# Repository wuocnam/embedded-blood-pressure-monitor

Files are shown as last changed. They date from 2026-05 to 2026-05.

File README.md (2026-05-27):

z7873015730073_17597a3d94fae7621c3b929b31e877bd# Embedded Blood Pressure Monitor

A real-time, non-invasive blood pressure monitoring system utilizing an embedded microcontroller and a custom-designed analog front-end for high-precision sensor data acquisition.

## 📸 Product Showcase
z7873014103155_68d4da9852d3bea1b45f12b7498baded
z7873015730836_ad06e7b14a9b0673478aa2cc813ee6c5

## 🛠️ Hardware & System Design
- **Microcontroller:** Arduino Nano (ATmega328P) with 16x2 LCD UI.
- **Pressure Sensor:** MPS20N0040D (0-40kPa).
- **Custom Analog Front-End (Signal Conditioning):** - High-precision instrumentation amplification using **AD620**.
  - Multi-stage active filtering using **LM741** Op-Amps.
- **Power Management:** Dual power supply design using **LM7805** (+5V) and **ICL7660S** (-5V for Op-Amp symmetrical rails).
- **Power Drivers:** Transistor-based driving circuits (**TIP41C**, **2N2222**) with flyback protection for actuators.
- **Actuators:** Mini air pump, solenoid release valve, and speaker.

## 📂 Repository Structure
- `/hardware`: Contains schematic snippets demonstrating the custom signal conditioning and power distribution networks.
- `/firmware`: Embedded C/C++ source code for sensor calibration, UI control, and actuator management.

## 🚀 Key Signal Routing
- **MPS Sensor Output** -> AD620 Instrumentation Amp -> LM741 Active Filters -> **Arduino ADC0**
- **Motor/Valve Control** -> Arduino D2, D3 -> TIP41C Driver Network

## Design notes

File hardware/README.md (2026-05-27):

Contains Altium schematic and PCB layout files.

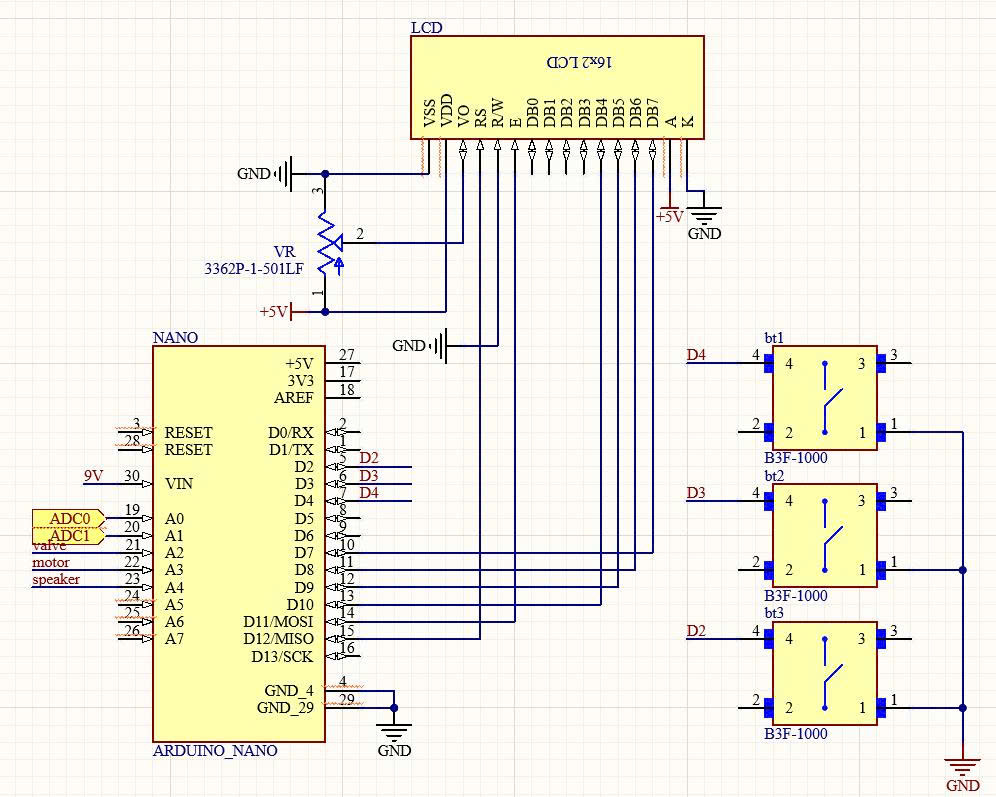
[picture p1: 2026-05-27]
hardware/z7873002787466_9863b803301838057b1b3febb424fb58.jpg

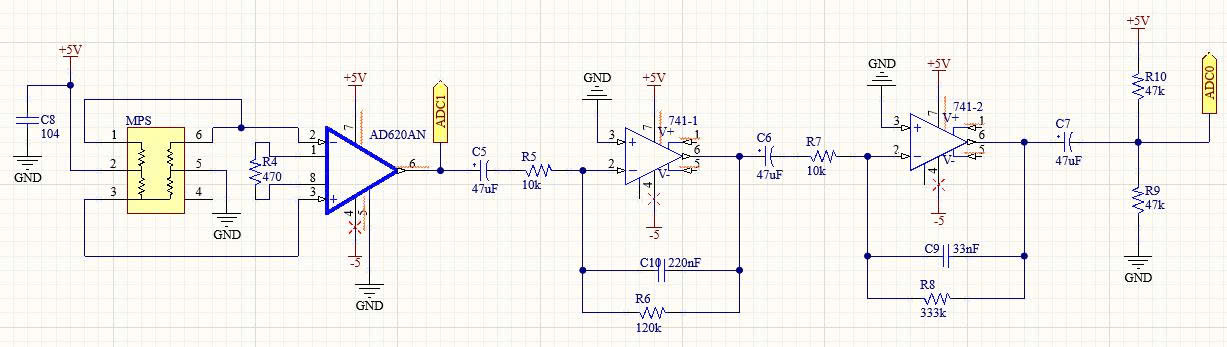
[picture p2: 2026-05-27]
hardware/z7873003652954_3d97f664d1a321c22de6d83c76b436e1.jpg

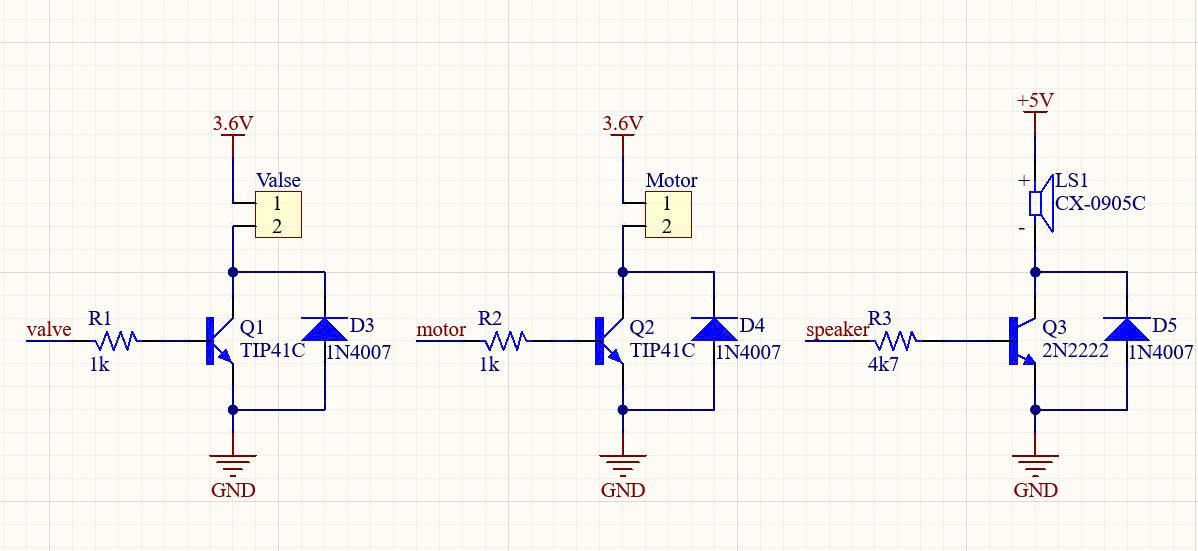
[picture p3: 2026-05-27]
hardware/z7873000200435_f1b9de5734167418a74198fc22bee216.jpg

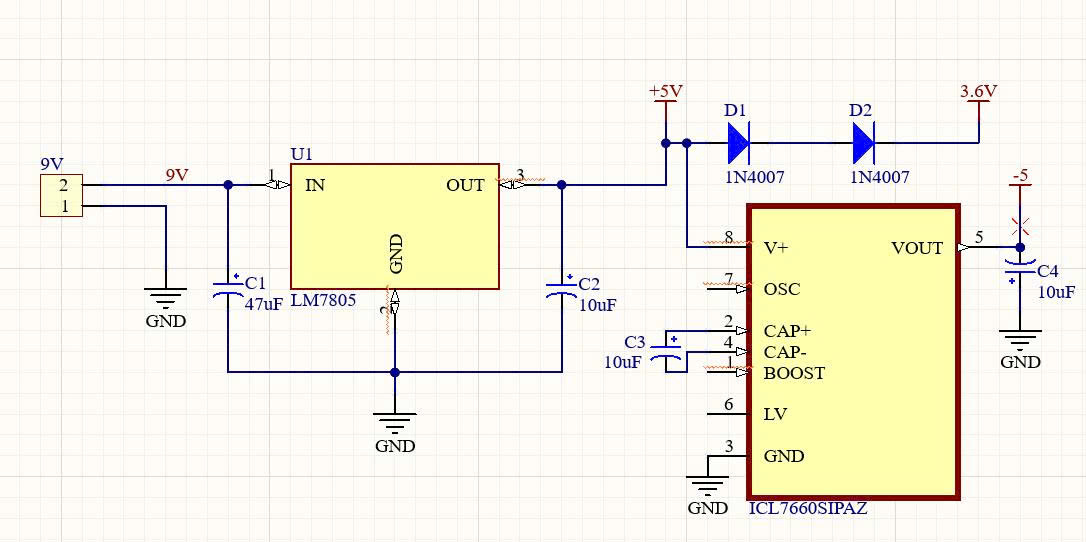
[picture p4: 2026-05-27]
hardware/z7873000130149_b3070aff2e2c831d72ec8909d467a5be.jpg

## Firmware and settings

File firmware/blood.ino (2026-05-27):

#include <avr/interrupt.h>
#include <LiquidCrystal.h>

#define on HIGH
#define off LOW

#define startState 0
#define inflate1State 1
#define inflate2State 2
#define deflateState 3
#define displayState 4
#define resetState 5

#define Sys_Measure 6
#define Rate_Measure 7
#define dias_Cal 8

#define valve A2
#define motor A3
#define speaker A4

#define bt_start 4
#define bt_stop 3
#define bt_resume 2

#define ADC0 A0
#define ADC1 A1

LiquidCrystal lcd(12,11,10,9,8,7);

unsigned char currentState;
unsigned char meas_state;

volatile unsigned int timepress0 = 0;
volatile unsigned int timepress1 = 0;
volatile unsigned int timepress2 = 0;

volatile unsigned int timing = 0;
volatile unsigned int timerate = 0;
volatile unsigned int timecount = 0;
volatile unsigned int timedeflate = 0;

volatile unsigned int speaker_timer = 0;

float Vref = 5.0;
float DC_gain = 105;

int data;
float adc_data;
float former;

float filtered_adc0 = 0;
float filtered_adc1 = 0;

float pressure = 0;
float maxpressure = 80;

float systolic = 0;
float diastolic = 0;
float pulse_per_min = 0;

float total_pulse_period = 0;

unsigned char count_average = 0;
unsigned char countpulse = 0;
unsigned char sys_count = 0;
unsigned char stop_count = 0;

float TH_sys = 4.9;
float TH_rate = 2.5;

static inline unsigned int read_u16(volatile unsigned int *v)
{
  unsigned int tmp;

  noInterrupts();
  tmp = *v;
  interrupts();

  return tmp;
}

static inline void write_u16(volatile unsigned int *v,
                             unsigned int val)
{
  noInterrupts();
  *v = val;
  interrupts();
}

void start_state(void);
void inflate1_state(void);
void inflate2_state(void);
void deflatestate(void);
void display_state(void);
void reset_state(void);

void pressuremeasure(void);
void sysmeasure(void);
void ratemeasure(void);
void diascal(void);

void read_adc(int Channel);

void setup()
{
  Serial.begin(9600);

  ADCSRA = (ADCSRA & 0xF8) | 0x07;

  pinMode(bt_start, INPUT_PULLUP);
  pinMode(bt_stop, INPUT_PULLUP);
  pinMode(bt_resume, INPUT_PULLUP);

  pinMode(motor, OUTPUT);
  pinMode(valve, OUTPUT);
  pinMode(speaker, OUTPUT);

  digitalWrite(motor, off);
  digitalWrite(valve, off);
  digitalWrite(speaker, LOW);

  lcd.begin(16,2);

  lcd.setCursor(0,0);
  lcd.print("White: Start");

  lcd.setCursor(0,1);
  lcd.print("Grey: Stop");

  cli();

  TCCR1A = 0;
  TCCR1B = 0;
  TIMSK1 = 0;

  TCCR1B |= (1 << WGM12);
  TCCR1B |= (1 << CS11) | (1 << CS10);

  OCR1A = 249;

  TIMSK1 |= (1 << OCIE1A);

  sei();

  write_u16(&timing,40);

  currentState = startState;
  meas_state = Sys_Measure;
}

void loop()
{
  switch(currentState)
  {
    case startState:
      start_state();
      break;

    case inflate1State:
      inflate1_state();
      break;

    case inflate2State:
      inflate2_state();
      break;

    case deflateState:
      deflatestate();
      break;

    case displayState:
      display_state();
      break;

    case resetState:
      reset_state();
      break;
  }
}

ISR(TIMER1_COMPA_vect)
{
  if(digitalRead(bt_start) == LOW)
    timepress0++;

  if(digitalRead(bt_stop) == LOW)
    timepress1++;

  if(digitalRead(bt_resume) == LOW)
    timepress2++;

  timecount++;
  timedeflate++;

  if(speaker_timer > 0)
  {
    digitalWrite(speaker,HIGH);
    speaker_timer--;
  }
  else
  {
    digitalWrite(speaker,LOW);
  }

  if(timing > 0)
    timing--;

  if(timerate < 65535)
    timerate++;
}

void start_state(void)
{
  if((digitalRead(bt_start) == LOW) &&
     (read_u16(&timepress0) > 30))
  {
    write_u16(&speaker_timer,100);

    pressure = 0;

    systolic = 0;
    diastolic = 0;
    pulse_per_min = 0;

    total_pulse_period = 0;

    count_average = 0;
    countpulse = 0;
    sys_count = 0;
    stop_count = 0;

    filtered_adc0 = 0;
    filtered_adc1 = 0;

    former = TH_sys - 0.01;

    meas_state = Sys_Measure;

    lcd.clear();

    lcd.setCursor(0,0);
    lcd.print("Inflating");

    digitalWrite(valve,off);

    digitalWrite(motor,on);

    currentState = inflate1State;

    write_u16(&timepress0,0);
    write_u16(&timecount,0);
  }
}

void inflate1_state(void)
{
  if(read_u16(&timecount) >= 1000)
  {
    lcd.setCursor(0,1);
    lcd.print("P=");
    lcd.print(pressure);
    lcd.print("     ");

    write_u16(&timecount,0);
  }

  if((digitalRead(bt_stop) == LOW) &&
     (read_u16(&timepress1) > 30))
  {
    digitalWrite(motor,off);
    digitalWrite(valve,off);

    currentState = resetState;

    write_u16(&timepress1,0);
  }
  else
  {
    currentState = inflate2State;
  }
}

void inflate2_state(void)
{
  read_adc(1);

  pressure = (adc_data / DC_gain) * 2000;

  Serial.print("Pressure: ");
  Serial.println(pressure);

  if(pressure >= maxpressure)
    stop_count++;
  else
    stop_count = 0;

  if(stop_count >= 5)
  {
    lcd.clear();

    lcd.setCursor(0,0);
    lcd.print("Deflating");

    digitalWrite(motor,off);

    delay(100);

    currentState = deflateState;

    write_u16(&timedeflate,0);
  }
  else
  {
    currentState = inflate1State;
  }
}

void deflatestate(void)
{
  unsigned int timedeflate_local =
    read_u16(&timedeflate);

  if(timedeflate_local >= 100)
  {
    write_u16(&timedeflate,0);
    timedeflate_local = 0;
  }

  if(timedeflate_local < 50)
  {
    digitalWrite(valve,on);
  }
  else
  {
    digitalWrite(valve,off);
  }

  if((digitalRead(bt_stop) == LOW) &&
     (read_u16(&timepress1) > 30))
  {
    digitalWrite(motor,off);
    digitalWrite(valve,off);

    currentState = resetState;

    write_u16(&timepress1,0);
  }

  pressuremeasure();
}

void pressuremeasure(void)
{
  if(read_u16(&timing) != 0)
    return;

  switch(meas_state)
  {
    case Sys_Measure:
      sysmeasure();
      break;

    case Rate_Measure:
      ratemeasure();
      break;

    case dias_Cal:
      diascal();
      break;
  }
}

void sysmeasure(void)
{
  read_adc(0);

  read_adc(1);

  pressure = (adc_data / DC_gain) * 2000;

  if(former <= TH_sys &&
     adc_data > TH_sys)
  {
    sys_count++;
  }

  former = adc_data;

  if(sys_count >= 2)
  {
    systolic = pressure;

    meas_state = Rate_Measure;

    former = TH_rate - 0.01;

    count_average = 0;
    countpulse = 0;

    total_pulse_period = 0;

    write_u16(&timerate,0);
  }

  if(read_u16(&timecount) >= 1000)
  {
    lcd.clear();

    lcd.setCursor(0,0);
    lcd.print("Measuring");

    lcd.setCursor(0,1);
    lcd.print(pressure);

    write_u16(&timecount,0);
  }
}

void ratemeasure(void)
{
  read_adc(0);

  if(read_u16(&timerate) > 5000)
  {
    pulse_per_min = 0;

    meas_state = dias_Cal;

    return;
  }

  if(former < TH_rate &&
     adc_data > TH_rate &&
     read_u16(&timerate) > 450)
  {
    if(countpulse == 0)
    {
      write_u16(&timerate,0);
      countpulse = 1;
    }
    else
    {
      total_pulse_period +=
        read_u16(&timerate);

      write_u16(&timerate,0);

      count_average++;
    }

    write_u16(&speaker_timer,30);
  }

  former = adc_data;

  if(count_average >= 5)
  {
    pulse_per_min =
      (5.0 * 60000.0) /
      total_pulse_period;

    lcd.clear();

    lcd.setCursor(0,0);
    lcd.print("Pulse");

    lcd.setCursor(0,1);
    lcd.print(pulse_per_min);

    meas_state = dias_Cal;
  }
}

void diascal(void)
{
  read_adc(1);

  pressure = (adc_data / DC_gain) * 2000;

  diastolic = pressure;

  digitalWrite(valve,off);

  write_u16(&speaker_timer,500);

  currentState = displayState;

  write_u16(&timecount,0);
}

void display_state(void)
{
  if(read_u16(&timecount) >= 1000)
  {
    lcd.clear();

    lcd.setCursor(0,0);
    lcd.print("S:");
    lcd.print(systolic);

    lcd.setCursor(9,0);
    lcd.print("D:");
    lcd.print(diastolic);

    lcd.setCursor(0,1);
    lcd.print("HR:");
    lcd.print(pulse_per_min);

    write_u16(&timecount,0);
  }

  if((digitalRead(bt_resume) == LOW) &&
     (read_u16(&timepress2) > 30))
  {
    lcd.clear();

    lcd.setCursor(0,0);
    lcd.print("White: Start");

    lcd.setCursor(0,1);
    lcd.print("Grey: Stop");

    currentState = startState;

    write_u16(&timepress2,0);
  }
}

void reset_state(void)
{
  lcd.setCursor(0,0);
  lcd.print("Emergency Stop");

  lcd.setCursor(0,1);
  lcd.print("Red: Resume ");

  if((digitalRead(bt_resume) == LOW) &&
     (read_u16(&timepress2) > 30))
  {
    lcd.clear();

    lcd.setCursor(0,0);
    lcd.print("White: Start");

    lcd.setCursor(0,1);
    lcd.print("Grey: Stop");

    currentState = startState;

    write_u16(&timepress2,0);
  }
}

void read_adc(int Channel)
{
  int buf[5];

  for(int i=0;i<5;i++)
  {
    long sum = 0;

    for(int j=0;j<16;j++)
    {
      if(Channel == 0)
        sum += analogRead(ADC0);
      else
        sum += analogRead(ADC1);
    }

    buf[i] = sum / 16;
  }

  for(int i=0;i<4;i++)
  {
    for(int j=i+1;j<5;j++)
    {
      if(buf[j] < buf[i])
      {
        int t = buf[i];
        buf[i] = buf[j];
        buf[j] = t;
      }
    }
  }

  data = buf[2];

  adc_data =
    (float)data * Vref / 1023.0;

  if(Channel == 0)
  {
    filtered_adc0 =
      0.9 * filtered_adc0 +
      0.1 * adc_data;

    adc_data = filtered_adc0;
  }
  else
  {
    filtered_adc1 =
      0.9 * filtered_adc1 +
      0.1 * adc_data;

    adc_data = filtered_adc1;
  }

  write_u16(&timing,40);

  Serial.print(adc_data);
  Serial.print(",");
  Serial.println(pressure);
}
